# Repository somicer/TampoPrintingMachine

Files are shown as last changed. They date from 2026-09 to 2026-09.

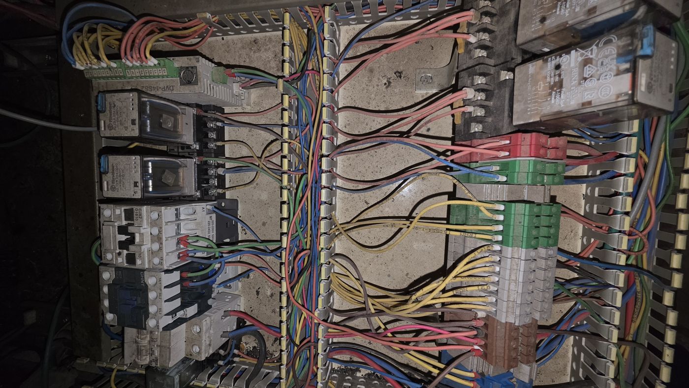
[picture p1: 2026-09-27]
docs/field_photos/panel_overview.jpg

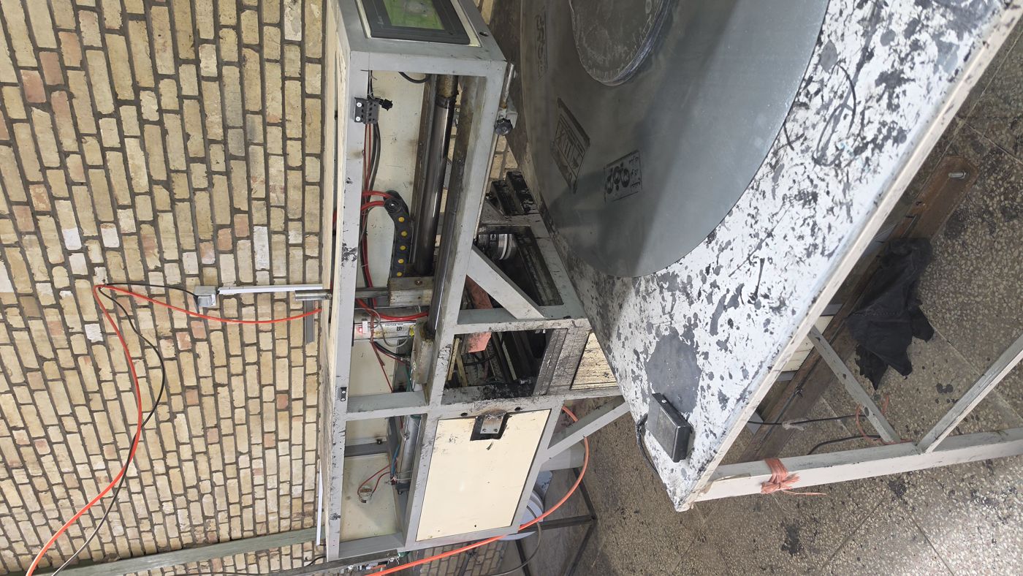
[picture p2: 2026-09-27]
docs/field_photos/machine_overview.jpg

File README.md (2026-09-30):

# سیستم کنترل دستگاه چاپ تامپو کاپ بسته‌ی بزرگ (Large-Format Closed-Cup Pad Printer)

کنترلر: **Delta DVP-28SV211T** · HMI: **Delta DOP-107BV** · درایور: **Leadshine CL57** + استپر کلوزلوپ NEMA24 · Z: پنوماتیک SMC MGPM

| فایل | محتوا |
|---|---|
| [docs/01_design_review.md](docs/01_design_review.md) | **نقد فنی طرح: مشکلات و پیشنهادها** (مطالعه‌ی آن پیش از ساخت ضروری است) |
| [docs/02_io_map.md](docs/02_io_map.md) | جدول کامل X، Y، M، D و T |
| [docs/03_state_machine.md](docs/03_state_machine.md) | ماشین وضعیت: هومینگ، اتومات، جوهرزنی و دستی |
| [docs/04_plc_program.md](docs/04_plc_program.md) | توضیح کد نردبانی، اینترلاک‌های ضدبرخورد و چک‌لیست راه‌اندازی |
| [docs/05_hmi.md](docs/05_hmi.md) | ساختار صفحات HMI، سطوح دسترسی و Recipe |
| [docs/06_electrical_safety_troubleshooting.md](docs/06_electrical_safety_troubleshooting.md) | تغذیه، ضد نویز، گراندینگ، مدار ایمنی، جدول آلارم‌ها و عیب‌یابی |
| [plc/TampoPrinter_SV2.il](plc/TampoPrinter_SV2.il) | برنامه‌ی کامل PLC (Instruction List) |
| [hmi/tag_list.csv](hmi/tag_list.csv) | فهرست Tagهای HMI |
| [hmi/hmi_mockup.html](hmi/hmi_mockup.html) | **نمونه‌ی تعاملی ۹ صفحه‌ی HMI** با آدرس هر شیء |
| [plc/TampoPrinter_SV2_clean.txt](plc/TampoPrinter_SV2_clean.txt) | برنامه‌ی PLC بدون توضیحات برای WPLSoft |
| [tools/plc_sim.py](tools/plc_sim.py) | شبیه‌ساز و تست خودکار برنامه‌ی PLC |
| [docs/07_bom_cost_estimate.md](docs/07_bom_cost_estimate.md) | برآورد هزینه‌ی قطعات (BOM) |
| [bom/bom_estimate.csv](bom/bom_estimate.csv) | فهرست قطعات و قیمت برای Excel |
| [docs/08_field_data_redesign.md](docs/08_field_data_redesign.md) | **داده‌های دستگاه موجود و طراحی از صفر** (معتبرترین بخش) |
| [docs/09_final_bom.md](docs/09_final_bom.md) | **لیست خرید نهایی طرح جدید** |
| [docs/10_operators_shifts_erp.md](docs/10_operators_shifts_erp.md) | **ورود کارگر، شیفت‌ها و ارسال آمار به ERP** |
| [tools/erp_gateway.py](tools/erp_gateway.py) | دروازه‌ی Modbus TCP به ERP |
| [docs/11_test_report.md](docs/11_test_report.md) | **گزارش تست نقطه‌به‌نقطه** (خودکار) |
| [docs/12_zones_error_handling.md](docs/12_zones_error_handling.md) | **مناطق ممنوع، مدیریت خطا و بازیابی نرم‌افزاری** |
| [tools/test_suite.py](tools/test_suite.py) | مجموعه‌ی تست (۴۶ سناریو، موازی) |
| [tools/axis_sizing.py](tools/axis_sizing.py) | محاسبه‌ی سرعت پیک، گشتاور، نسبت اینرسی و نیروی جک |
| [docs/13_3d_design.md](docs/13_3d_design.md) | **طراحی سه‌بعدی کل دستگاه** (قطعات و اسکلت)، راهنمای AutoCAD و ساخت |
| [cad/tampo_machine.py](cad/tampo_machine.py) | مدل پارامتریک CadQuery: خروجی STEP، DXF ورق‌ها، نقشه‌ی کلی، لیست برش و بررسی تداخل |
| [cad/out/tampo_viewer.html](cad/out/tampo_viewer.html) | نمایشگر سه‌بعدی با انیمیشن چرخه‌ی چاپ (در مرورگر باز کنید) |

## مهم‌ترین نتیجه‌ها (طرح نهایی بر اساس دستگاه موجود)

1. **Z پنوماتیک می‌ماند:** جک **SC63×100** (حدود ۱۶۰ کیلوگرم نیرو، مثل دستگاه فعلی)، به همراه شیر 3/8، شیر تخلیه‌ی سریع، رگولاتور جدا و پایلوت‌چک.
2. **X:** استپر کلوزلوپ ۴ N·m با گیربکس ۱:۳ و تسمه‌ی HTD5M عرض ۲۵. کورس ۷۵۰ mm با ریل HGR20 به طول ۱۰۶۰: پد تا ۴۴ سانت از بدنه بیرون می‌آید و روی **دیسک پلاستیکی** (مثلاً Ø1000/500) روی میز گردانِ پیچ‌شده به دستگاه چاپ می‌کند. جرم متحرک ۲۲ kg.
3. **Y:** همان استپر، مستقیم، روی **همان تسمه‌ی ۲۰ mm** دستگاه فعلی با پولی ۲۴ دندانه.
4. **سیکل:** جوهرزنی موازی، هم‌پوشانی حرکت X و Z، و برداشت زودتر. از **۱۰.۵ ثانیه** به حدود **۴.۵ تا ۵.۵ ثانیه**.
5. **ایمنی:** پرده‌ی نوری و رله‌ی ایمنی الزامی‌اند. اپراتور بعد از هر چاپ دستش را زیر پد می‌برد.
6. **اینترلاک ضدبرخورد:** سنسور ارتفاع امن (X20) و آلارم‌های A10 و A17 که قانون «پد روی سطح = X ساکن» را تضمین می‌کنند.

> ⚠️ کد یک **طرح مرجع** است و روی سخت‌افزار واقعی تست نشده است. شماره‌ی رجیسترها و بیت‌های ویژه‌ی SV2 را با دفترچه‌ی فریمور خودتان تطبیق دهید. PLC استاندارد جایگزین مدار ایمنی نیست.

## اجرای محاسبات

```bash
python3 cad/tampo_machine.py      # مدل سه‌بعدی و همه‌ی خروجی‌های ساخت (نیاز: pip install cadquery ezdxf)
python3 tools/axis_sizing.py
```

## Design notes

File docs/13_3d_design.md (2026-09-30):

# ۱۳. طراحی سه‌بعدی دستگاه (قطعات و اسکلت)

> **نمایشگر سه‌بعدی:** فایل [`cad/out/tampo_viewer.html`](../cad/out/tampo_viewer.html) را در مرورگر باز کنید. چرخه‌ی چاپ را پخش کنید، قطعه‌ها را بچرخانید، باز کنید، برش بزنید و روی هر قطعه کلیک کنید.
> **مدل اصلی:** [`cad/tampo_machine.py`](../cad/tampo_machine.py) (پارامتریک، CadQuery). هر عددی را در بالای این فایل عوض کنید و دوباره اجرا کنید تا همه‌ی فایل‌ها دوباره ساخته شوند.

## ۱۳-۱ چه فایل‌هایی ساخته شد و هر کدام به چه درد می‌خورد

| فایل | برای چه |
|---|---|
| `cad/out/tampo_assembly.step` | **کل دستگاه** با ۲۱۲ قطعه‌ی جامد و رنگی (همراه میز دیسک و پیچ‌ها). در AutoCAD، SolidWorks، Inventor، Fusion یا FreeCAD (رایگان) باز می‌شود |
| `cad/out/parts_step/*.step` | **هر قطعه‌ی ساختنی جدا** (لوله‌ها `T..`، ورق‌ها `P..`، قطعات تراش/فرز `M..`) در مختصات خودش، برای نقشه‌کشی قطعه‌به‌قطعه |
| `cad/out/dxf/*.dxf` | **نقشه‌ی تخت ورق‌ها** در مقیاس ۱:۱ میلی‌متر، با همه‌ی سوراخ‌ها و شیارها. مستقیم به کارگاه برش لیزر یا واترجت بدهید |
| `cad/out/tampo_GA.dxf` | **نقشه‌ی کلی** در سه نما (کنار، روبه‌رو و بالا) با خطوط پنهان و اندازه‌های اصلی |
| `cad/out/cut_list.csv` | **لیست برش لوله‌ها:** پروفیل، طول، تعداد و تعداد شاخه‌ی ۶ متری |
| `cad/out/parts_list.csv` | **لیست کامل قطعات:** کد، نام، جنس، اندازه، تعداد، جرم و روش ساخت (با Excel باز می‌شود) |
| `cad/out/check_report.md` | **گزارش بررسی خودکار:** تداخل، فاصله‌ها، سفتی سازه، جرم‌ها و کنترل دوباره‌ی موتور |

**کدگذاری قطعات:**
* `T` = لوله‌ی اسکلت (برش اره و جوش).
* `P` = ورق (برش لیزر، سپس سوراخ‌کاری یا قلاویز).
* `M` = قطعه‌ی تراش یا فرز.
* `B` = قطعه‌ی خریدنی. شکل آن‌ها نزدیک به واقعی است (بخش ۱۳-۱۱)، ولی ابعاد نصب را با کاتالوگ تطبیق دهید.
* `F` = پیچ و مهره. تعداد هر ردیف در `parts_list.csv` آمده است.

## ۱۳-۲ کار با AutoCAD

1. **باز کردن مدل سه‌بعدی:** فرمان `IMPORT` و انتخاب `tampo_assembly.step`. هر قطعه یک Solid سه‌بعدی می‌شود.
2. **نقشه‌ی دوبعدی با اندازه:** در AutoCAD کامل (نه LT)، فرمان `VIEWBASE` روی مدل وارد‌شده یا روی هر فایل `parts_step/*.step`. نماهای روبه‌رو، بالا، کنار و ایزومتریک خودکار ساخته می‌شوند. بعد با `DIM` اندازه بگذارید. اگر مدل را عوض کنید، نماها به‌روز می‌شوند.
3. **ورق‌ها:** فایل‌های `dxf/*.dxf` را مستقیم باز کنید. لایه‌ی `CUT` لبه‌ی بیرونی و بریدگی‌هاست، `HOLES` سوراخ‌ها و شیارها، `DIM` اندازه‌ها و `TEXT` مشخصات.
4. **AutoCAD LT** مدل سه‌بعدی را باز نمی‌کند. با LT از `tampo_GA.dxf` و فایل‌های `dxf/` استفاده کنید.

> **سوراخ‌های قلاویزی:** در DXF قطر **مته‌ی قلاویز** کشیده شده، مثلاً Ø4.2 برای M5، Ø6.8 برای M8 و Ø10.2 برای M12. این سوراخ‌ها را با لیزر نبرید. جای آن‌ها را علامت بزنید و در کارگاه مته و قلاویز کنید. توضیح هر ورق در ستون `note` فایل `parts_list.csv` آمده است.

## ۱۳-۳ چیدمان دستگاه

**قطعه‌کار:** دیسک پلاستیکی به ضخامت ۲ mm، مثلاً قطر بیرونی ۱۰۰۰ و قطر داخلی ۵۰۰ mm. دیسک روی **میزی بیرون از بدنه‌ی دستگاه** قرار می‌گیرد. پد از بدنه **بیرون می‌آید** و روی حلقه‌ی دیسک چاپ می‌کند. اپراتور بعد از هر چاپ دیسک را می‌چرخاند.

```
  نمای کنار (از سمت چپ)
                    ◄─ بدنه 600 ─►◄──────── پد تا 440 mm بیرون می‌آید ────────►
                    ┌──────────────╥════════ دو تیر X (یک‌سرآزاد) ═════════════╗
       موتور X ▣════╪══ تسمه ═════╬═[کالسکه+جک Z]══════════════════════ هرزگرد ╣
                    │ پرتال عقب    ║ ستون جلو    │ پد                          │
                    │  کلیشه + کاپ ║ (پنجره‌ی پد) ▼                            │
                    │ ═════════════╣      ┌──────────────── دیسک Ø1000 ────────────┐
                    │  قاب SHS60   ║══════╡ میز گردان روی بلبرینگ (Lazy Susan)     │
                    │              ║ لوله‌ی اتصال │  قاب میز SHS60                │
                    └──────────────╨══════════════┴───────────────────────────────┘
                                   ↑ میز دیسک با ۴ لوله به بدنه پیچ می‌شود
```

| اندازه | مقدار (mm) |
|---|---:|
| ابعاد کلی (بدنه، تیرها، میز دیسک، تابلو، HMI) | حدود 1870 × 1300 × 1650 |
| بدنه‌ی دستگاه | 600 × 950، ارتفاع قاب 880 |
| **ارتفاع کار** (روی کلیشه = روی دیسک) | **945** |
| کورس کامل X | **750** (پد تا **440** جلوتر از بدنه) |
| محل برداشت / چاپ پیش‌فرض (دیسک Ø1000/500، وسط حلقه، شعاع 375) | X = 50 / X = 495 |
| دیسک Ø800/400 و Ø600/300 (با همان مرکز میز) | X = 570 و X = 645 |
| جای دست بالای دیسک تا زیر تیرها | 272 |
| جرم بدنه (بدون تابلو) / میز دیسک | حدود ۳۲۵ / ۱۳۰ کیلوگرم |

**محورها:**
* **X** جهت حرکت پد به سمت میز دیسک است.
* **محور کاپ** (Y در برنامه‌ی PLC) مثل دستگاه فعلی **۹۰ درجه با X** است. کلیشه در جهت Y قرار دارد و کاپ ۳۷۰ mm به سمت چپ می‌رود.
* **Z** رو به بالاست.

**محل چاپ برای هر دیسک:** مرکز دیسک همیشه روی **مرکز میز گردان** است. برای هر قطر، فقط عدد «محل چاپ» (D502) روی صفحه‌ی اصلی HMI عوض می‌شود:

**محل چاپ = 1160 − 290 − شعاع چاپ**

مثلاً برای دیسک Ø1000/500 و چاپ وسط حلقه (شعاع 375): 1160 − 290 − 375 = **495**. در دستورهای کار (Recipe) نمونه‌ی سه قطر آماده گذاشته شده است.

## ۱۳-۴ تصمیم‌های طراحی و دلیلشان

| بخش | طراحی | چرا |
|---|---|---|
| **بدنه** | بدنه‌ی کوتاه (۶۰۰ mm) که فقط ایستگاه جوهر، موتورها و برق را دارد. قاب جوشی **SHS 60×60×4** | هرچه کلیشه به جلوی بدنه نزدیک‌تر باشد، مسیر پد تا دیسک کوتاه‌تر است |
| **تیرهای X** | دو تیر **RHS 120×60×5** روی **پرتال عقب** و **دو ستون جلو که درست زیر تیرها هستند**. تیرها **۶۶۰ mm از ستون جلو بیرون می‌زنند** و سرشان با یک عرضی به هم بسته است | پد از **پنجره‌ی** بین دو ستون جلو بیرون می‌رود. تیر بزرگ‌تر از قبل انتخاب شد چون حالا **یک‌سرآزاد** است. در بیشترین دسترسی و با فشار کامل جک، خیز فقط **۰.۰۹ mm** است |
| **نیرو در ستون جلو** | پیچ تیر به ستون جلو **کشش** دارد (حدود ۲ kN در بیشترین دسترسی) | فشار چاپ پد را به بالا هل می‌دهد و سر تیرها را بلند می‌کند. ۴ پیچ M10 در هر اتصال چند برابر این نیرو را تحمل می‌کنند |
| **میز دیسک** | قاب **SHS 60×60×4** با **۴ لوله‌ی اتصال پیچی به بدنه** (بالا و پایین). صفحه‌ی گردان Ø1050 روی **بلبرینگ گردان Ø500**. **حلقه‌ی مرکزگیر** قابل تعویض برای هر قطر داخلی. **پین شاخص** برای سه چاپ با زاویه‌ی ۱۲۰ درجه | اگر میز جدا باشد، فشار چاپ **جلوی دستگاه را از زمین بلند می‌کند** (محاسبه در گزارش: ۲۰۱۹ N·m گشتاور بلندکننده در برابر ۱۳۳۱ N·m وزن). با اتصال پیچی، نیرو داخل فولاد بسته می‌شود. صفحه‌ی گردان چرخاندن دیسک ۱ متری را راحت و دقیق می‌کند |
| **ریل X** | دو **HGR20 طول ۱۰۶۰** (کورس ۷۵۰ + جای اضافه‌ی ۴۰ mm در هر سر) روی **تسمه‌ی فولادی سنگ‌خورده 40×15** | تسمه‌ی سنگ‌خورده با شیم تراز می‌شود و به فرز کردن کل اسکلت نیازی نیست |
| **کالسکه و هد Z** | همان طرح قبل: صفحه‌ی آلومینیوم ۱۵ mm، جک **SC63×100**، دو میله‌ی **Ø25** در **LMF25**، مفصل شناور، و اسلاید دستی ارتفاع پد با پیچ فشاری M12 | جرم متحرک ۲۱.۹ kg |
| **سنسورهای Z** | به‌جای سنسور مگنتی روی جک: **سه سنسور القایی M12** (PR12-4DN) روی براکت شیاری `P17` زیر کالسکه، رو به یک **تسمه‌ی آهنی 3×20×40** (`P16`) که به صفحه‌ی سر پیچ شده. طول تسمه‌ی آهنی = ناحیه‌ی امن | سنسور ارتفاع امن (X20) حالا **ناحیه‌ای** است: از بالا تا ارتفاع امن پیوسته روشن است. PLC فقط `M26 = X20` می‌خواند؛ قطع سیم یا افتادن تسمه‌ی آهنی یعنی «ناامن» و X حرکت نمی‌کند. نقطه‌های قطع در بخش ۸ گزارش بررسی است |
| **محرک X** | تسمه‌ی HTD5M عرض ۲۵ **بین دو ریل** (۱۰۰ mm کنار مرکز). موتور و گیربکس **پشت کالسکه**. هرزگرد با شیار کشش روی **عرضی سر تیرها** | بخش ۱۳-۱۰ |
| **ایستگاه جوهر** | کلیشه در جهت Y، کاپ Ø140 روی بازو با ۳ پین فنری، ریل **HGR15** پشت کلیشه، و تسمه‌ی ۲۰ با موتور مستقیم | کاپ آزادانه روی کلیشه صاف می‌نشیند |
| **برق** | تابلو ۶۰×۸۰ روی بدنه‌ی راست. **HMI در گوشه‌ی جلو-راست، رو به میز دیسک**. یک E-Stop روی HMI و یکی روی پایه‌ی میز. پدال کنار میز | اپراتور کنار میز دیسک می‌ایستد |
| **محافظ‌ها** | بدنه با پلی‌کربنات بسته است، به‌جز **پنجره‌ی پد** در جلو. درب لولایی با سوئیچ ایمنی روی ایستگاه جوهر | دست فقط به دیسک و زیر مسیر پد می‌رسد |

## ۱۳-۵ بررسی‌های خودکار (نتیجه‌ی اجرای مدل)

جزئیات کامل در [`cad/out/check_report.md`](../cad/out/check_report.md) است.

* **تداخل:** قطعه‌های ثابت هیچ تداخلی ندارند. در **۷ حالت حرکتی** هیچ برخوردی نیست: خانه، برداشت با پد پایین، انتظار برداشت زودتر، **عبور پد از پنجره‌ی جلو**، چاپ روی دیسک، و بیشترین دسترسی با پد بالا و پایین.
* **فاصله‌ها:**
  * هد Z هنگام عبور از پنجره، ۵۰ mm با ستون‌های جلو فاصله دارد.
  * پد (بالا) ۲۰ mm بالای لبه‌ی پایین پنجره است.
  * پد (بالا) ۳۳ mm بالای بازوی کاپ است.
* **سفتی:** خیز سر تیرها زیر نیروی کامل جک (۱۵۹۰ N): ۰.۰۱ mm در چاپ دیسک Ø1000 و **۰.۰۹ mm** در بیشترین دسترسی.
* **موتور X:** جرم متحرک ۲۱.۹ kg است. گشتاور لازم ۰.۵۷ N·m در برابر ۱.۲ تا ۱.۵ N·m موجود، یعنی **۲.۱ تا ۲.۶ برابر حاشیه**. کورس بلندتر فقط زمان حرکت را بیشتر می‌کند و زور بیشتری نمی‌خواهد.
* **برنامه‌ی PLC:** مقدارهای پیش‌فرض عوض شد: برداشت ۵۰، چاپ ۴۹۵ و حد نرم‌افزاری X ۷۵۰ mm. هر ۵۷ سناریوی تست دوباره قبول شدند.

## ۱۳-۶ راهنمای ساخت

1. **لوله‌ها** را طبق `cut_list.csv` ببرید. همه‌ی برش‌ها ۹۰ درجه‌اند.

   | پروفیل | کل طول | تعداد شاخه‌ی ۶ متری |
   |---|---:|---:|
   | SHS 60×60×4 (بدنه و میز دیسک) | ۲۳.۸ متر | ۵ |
   | RHS 120×60×5 (تیرهای X) | ۳.۰ متر | ۱ |
   | SHS 40×40×3 | ۰.۹ متر | ۱ |

2. **ترتیب جوش:**
   1. قاب بدنه و قاب میز دیسک را **جدا** روی میز صاف جوش دهید.
   2. خال‌جوش بزنید، قطرها را بسنجید (اختلاف کمتر از ۲ mm)، و بعد جوش کامل ضربدری بدهید.
   3. ستون‌های جلو و پرتال عقب را جوش دهید.
3. **میز دیسک را به بدنه پیچ کنید**: ۴ لوله‌ی اتصال، هر سر با ورق فلنج `P61` (120×60×10) و ۲ پیچ M12 با مهره و واشر. پیش از سفت کردن، سطح میز گردان را با تراز روی **۹۴۳** بیاورید.
4. **تیرهای X** را پیچ کنید، جوش نکنید: ۴ پیچ M10 روی پرتال عقب و ۴ پیچ روی هر ستون جلو. بعد عرضی سر تیرها را ببندید.
5. **تراز کردن ریل‌ها:** ریل اول را با ساعت اندیکاتور صاف کنید (خطای کمتر از ۰.۰۲ mm). ریل دوم را نسبت به اولی موازی کنید و زیر تسمه‌ها شیم بگذارید.
6. **ورق‌ها** را از روی `dxf/` لیزر کنید. سوراخ‌های مته‌ی قلاویز را فقط علامت بزنید.
7. **تراشکاری:** میله‌های Ø25 (h6، سخت‌کروم)، پایه‌ی کلیشه (فرز و سنگ)، صفحه‌ی گردان (CNC)، و حلقه‌ی مرکزگیر POM برای هر قطر داخلی دیسک.
8. **رنگ:** اسکلت ضدزنگ و کوره‌ای (مدل RAL 7016). سطح ریل‌ها و پایه‌ی کلیشه را رنگ نکنید.

## ۱۳-۷ فرض‌ها: پیش از ساخت تأیید کنید

| مورد | فرض مدل | کجا اثر دارد |
|---|---|---|
| **کورس X** | **۷۵۰ mm** (پد تا ۴۴۰ mm جلوتر از بدنه). ریل **۱۰۶۰ mm**، یعنی حدود ۴۰ mm جای اضافه بعد از واگن‌ها در هر سر | اگر کورس عوض شد، عدد `x_travel` را در مدل عوض کنید. طول ریل (استاندارد HIWIN)، تیرها، تسمه و حد نرم‌افزاری خودکار حساب می‌شوند |
| میز دیسک | **جدید**، بخشی از دستگاه و پیچ‌شده به بدنه | اگر می‌خواهید از میز گرد فعلی استفاده کنید، آن را با لوله به بدنه ببندید یا دستگاه را با رول‌بولت به زمین محکم کنید (بخش ۴ گزارش) |
| فاصله‌ی لبه‌ی دیسک تا بدنه | ۶۰ mm | مرکز میز در X = 1160 |
| فلنج جلوی جک SC63 (FA) | ۴ سوراخ Ø9 در 50×100، سوراخ وسط Ø40 | صفحه‌ی کالسکه `P10` |
| گیربکس PLF60 1:3 | فلنج خروجی ۴×M5 روی PCD 70 | براکت موتور `P21` |
| استپر NEMA24 | ۴ سوراخ روی مربع 47.14 | براکت موتور کاپ `P33` |
| کاپ فعلی | قطر ۱۴۰، ارتفاع ۴۵ | بازوی کاپ `P31` |
| کلیشه | فولادی ضخیم ۱۰ mm | ضخامت پایه‌ی کلیشه `P30` |
| تسمه‌ی کاپ | همان تسمه‌ی گام ۵ عرض ۲۰ فعلی | پولی `B12` |

**برای عوض کردن هر فرض:** مقدار را در بخش `PARAMETERS` بالای `cad/tampo_machine.py` عوض کنید، مثلاً `reach`، `disc_od`، `disc_id` یا `disc_gap`. بعد `python3 cad/tampo_machine.py` را اجرا کنید (حدود ۱۰ ثانیه) تا همه‌ی فایل‌ها و بررسی‌ها دوباره ساخته شوند.

## ۱۳-۸ ⚠️ ایمنی: حالا خطر روی میز دیسک است

اپراتور بعد از **هر** چاپ دستش را روی دیسک، زیر مسیر پد می‌برد. میز باز است و حدود یک متر قطر دارد، پس **پرده‌ی نوری جلوی بدنه دیگر جای مفیدی ندارد** و در مدل حذف شد. پیشنهاد به ترتیب اهمیت:

1. **فرود دومرحله‌ای با نیروی کم (اصلی):** پد با فشار کم پایین می‌آید (نیروی کمتر از ۱۵۰ N که دست را له نمی‌کند). فقط وقتی سنسور «پایین» روشن شد، فشار کامل وصل می‌شود. این کار یک رگولاتور، یک شیر کوچک و تغییر کوچکی در برنامه‌ی PLC لازم دارد.
2. **شروع فقط وقتی دست بیرون است:** یک **اسکنر ایمنی لیزری** (Area Scanner) که ناحیه‌ی زیر مسیر پد روی میز را می‌پاید، **به‌جای پرده‌ی نوری**. گران‌تر از پرده‌ی نوری است، ولی برای میز باز مناسب‌تر است. در لیست خرید (بخش ۹) هنوز پرده‌ی نوری آمده است. اگر اسکنر را انتخاب کنید، آن ردیف عوض می‌شود.
3. **فشار چاپ را پایین بیاورید:** برای دیسک پلاستیکی ۲ میلی‌متری معمولاً فشار کامل ۵ بار لازم نیست. با رگولاتور Z، فشار را به کمترین مقداری برسانید که چاپ خوب می‌دهد. نیروی کمتر هم برای ایمنی و هم برای تیرها بهتر است.

> این تصمیم با شماست. تا یکی از راه‌های ۱ یا ۲ اجرا نشده، دستگاه **برای کار با دست زیر پد ایمن نیست**. سوئیچ ایمنی درب ایستگاه جوهر (`B61`) باید در مدار **رله‌ی ایمنی** سری شود.

## ۱۳-۹ قطعات مکانیکی خریدنی که در لیست خرید بخش ۹ نیستند

تعداد دقیق همه در `parts_list.csv` است.

* **کاپ:** ریل **HGR15 طول ۴۶۰** و یک واگن **HGH15CA**.
* **سنسورهای Z:** براکت `P17` و تسمه‌ی آهنی `P16` ساختنی‌اند. خود سه سنسور در لیست خرید بخش ۹ آمده است.
* **هد Z:** دو **LMF25UU**، دو میله‌ی **Ø25×210 سخت‌کروم**، **مفصل شناور M16×1.5**، **فلنج FA** جک، پیچ M12.
* **میز دیسک:** **بلبرینگ گردان (Lazy Susan) Ø500** با ظرفیت ۲۰۰ kg یا بیشتر، **صفحه‌ی گردان Ø1050** (MDF روکش‌دار یا کامپوزیت آلومینیوم)، **حلقه‌های مرکزگیر POM** برای هر قطر داخلی، و **پین شاخص فنری**.
* **اسکلت:** ده **پایه‌ی ترازشو M16** (۶ برای بدنه، ۴ برای میز)، و زیر هر پایه ورق کف `P62` با مهره‌ی M16 جوش‌شده.
* **محافظ‌ها:** ورق **پلی‌کربنات ۵ mm** (حدود ۱.۵ متر مربع)، لولا، **سوئیچ ایمنی درب**.
* **زنجیر کابل** 25×50 به طول حدود ۱.۷ m با سینی.
* **فولاد و آلومینیوم:** لوله‌ها طبق لیست برش، ورق فولادی ۱۰ تا ۱۵ mm، ورق آلومینیوم ۱۲ تا ۲۰ mm، تسمه‌ی فولادی 40×15، و بلوک ۴۵ mm برای پایه‌ی کلیشه.

## ۱۳-۱۰ آیا تسمه باید حتماً به وسط کالسکه وصل شود؟

**نه، با ریل‌های واگن‌دار (HGR) لازم نیست.** ولی هرچه نزدیک‌تر به مرکز باشد بهتر است.

* **چه اتفاقی می‌افتد؟** وقتی تسمه کنار مرکز کالسکه می‌کشد، علاوه بر هل دادن، کالسکه را کمی **می‌پیچاند**، مثل وقتی یک کشو را از گوشه‌اش می‌کشید. مقدار پیچش = نیرو × فاصله از مرکز.
* **چه کسی جلوی پیچش را می‌گیرد؟** ۴ واگن روی دو ریل. هر واگن HGR20 حدود **۱۷٬۷۵۰ نیوتن** ظرفیت دارد. در این طرح، پیچش فقط حدود **۳۰ نیوتن** روی هر واگن می‌اندازد، یعنی **کمتر از ۰.۲٪** ظرفیتش. پس هیچ مشکلی ایجاد نمی‌کند (جزئیات در بخش ۷ گزارش بررسی).
* **کجا مشکل‌ساز است؟** در **شفت گرد با بوش ساده** (مثل دستگاه فعلی شما). آنجا بوش لقی دارد و کشیدن از کنار باعث **کج شدن و گیر کردن** می‌شود، مثل کشوی قدیمی. قاعده‌ی تجربی این است که فاصله‌ی دو بوش در جهت حرکت حداقل ۲ برابر فاصله‌ی نیرو تا مرکز باشد. اگر محور X را با همان شفت‌های Ø45 فعلی بسازید، تسمه را حتماً **در وسط** بگذارید.
* **در این طرح چه کردیم:** تسمه را از بیرون ریل (۲۱۵ mm از مرکز) به **داخل، بین دو ریل (۱۰۰ mm از مرکز)** آوردیم تا پیچش نصف شود. وسطِ وسط ممکن نیست، چون جک Z و میله‌های راهنمای پد آنجا هستند.

## ۱۳-۱۱ جزئیات مدل و لیست پیچ و مهره

مدل حالا قطعه‌ها را با شکل نزدیک به واقعی نشان می‌دهد، تا هم نقشه‌ها گویاتر باشند و هم تداخل‌ها واقعی‌تر سنجیده شوند:

| قطعه | جزئیات در مدل |
|---|---|
| ریل HGR20 و HGR15 | مقطع با شیار کناری، سوراخ‌های خزینه‌دار با گام ۶۰، و پیچ‌های آلن داخل خزینه |
| واگن HGH20CA و HGH15CA | بدنه‌ی فولادی با ۴ سوراخ M5/M4، آب‌بند دو سر (قرمز)، و گریس‌خور |
| استپر NEMA24 | بدنه‌ی گوشه‌پخ، فلنج با ۴ سوراخ روی مربع 47.14، انکودر پشت با کانکتور، و محور |
| گیربکس PLF60 | فلنج مربعی خروجی با ۴ سوراخ روی PCD 70 و بدنه‌ی گرد |
| جک SC63×100 | دو درپوش مربعی ۷۵، لوله‌ی Ø70، ۴ تای‌راد با مهره، پیچ‌های کوشن، و درگاه‌ها |
| پولی‌ها | ۲۴ دندانه‌ی HTD 5M، دو فلنج، و توپی |
| تسمه‌ها | حلقه‌ی کامل دور دو پولی (رشته‌ی بالا داخل گیره‌ی کالسکه) |
| زنجیر کابل | حلقه‌های جدا با گام ۲۵ و خم U |
| شیر 4V320 | بدنه، دو کویل با کانکتور، و سه اتصال |
| بوش LMF25 / LMF20 | فلنج با ۴ سوراخ و بدنه |
| پایه‌ها | ورق کف جوشی `P62`، پایه‌ی ترازشو با کف لاستیکی، و مهره‌ی قفل |
| پرتال‌ها | ۴ **لچکی** ۱۰۰×۱۰۰×۸ (`P63`) در گوشه‌ی داخلی ستون و تیر عرضی، برای سفتی جانبی |
| میز دیسک | فلنج‌های پیچی `P61`، و **۳ سوراخ شاخص ۱۲۰ درجه** در صفحه‌ی گردان برای پین شاخص |
| تابلو، HMI، چراغ برج، E-Stop، FRL | درب با دریچه‌ی هوا، دستگیره و لولا، گلند کابل؛ صفحه‌ی لمسی و ۳ شستی؛ سه طبقه‌ی رنگی؛ قارچی قرمز |
| ورق‌های آلومینیومی | گوشه‌ی گرد (R6 تا R10) در مدل و در DXF |

**لیست پیچ و مهره (از `parts_list.csv`، کدهای `F`):**

| کد | پیچ | تعداد | کجا |
|---|---|---:|---|
| F01 | آلن M5×20 | 42 | ریل‌های X |
| F02 | آلن M5×25 | 16 | واگن‌های X به کالسکه |
| F03 | آلن M8×25 | 4 | فلنج جک |
| F04 | آلن M6×30 + مهره | 8 | بوش‌های LMF25 |
| F05 | آلن M6×20 | 6 | صفحه‌های کناری هد Z |
| F06 | آلن M12×25 | 2 | میله‌های راهنما به صفحه‌ی سر |
| F07 | آلن M10×30 + واشر | 4 | شیار تنظیم ارتفاع پد |
| F08 | آلن M8×20 + واشر | 8 | پایه‌ی براکت‌های موتور و هرزگرد |
| F09 | آلن M4×16 | 8 | ریل کاپ |
| F10 | آلن M4×12 | 4 | واگن کاپ |
| F11 | آلن M12×40 + مهره و واشر | 16 | اتصال میز دیسک |

پیچ‌های اتصال تیرهای X به پرتال و ستون جلو (M10، قلاویز در ورق جوشی)، پیچ‌های خزینه‌ی M8 تسمه‌ی ریل، و پیچ‌های کلیشه و محافظ‌ها **در مدل کشیده نشده‌اند**. هنگام خرید حدود ۲۰٪ به همه‌ی ردیف‌ها اضافه کنید.

> **یک اصلاح طراحی که همین بررسی پیدا کرد:** سوراخ‌های پیچ پایه‌ی براکت موتور X و هرزگرد، و پایه‌ی براکت‌های کاپ، **زیر دیواره‌ی عمودی براکت** افتاده بودند، جایی که پیچ اصلاً جا نمی‌شود. سوراخ‌ها به بیرون از دیواره منتقل شدند و DXF آن‌ها (`P20`، `P22`، `P33F`، `P34F`) به‌روز شد.

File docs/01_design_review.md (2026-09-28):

# ۱. نقد فنی طرح پیشنهادی: مشکلات و پیشنهادها

> ⚠️ **این بخش بر اساس اطلاعات اولیه (Gemini) نوشته شده است.** برای طرح جدید و قطعات نهایی، [بخش ۸](08_field_data_redesign.md) و [بخش ۹](09_final_bom.md) را ببینید. نکته‌های ایمنی، نویز و منطق کلی همچنان معتبرند.

> این بخش پیش از کد آمده است، چون چند مورد از مشکلات زیر روی **آدرس‌دهی I/O، لاجیک ایمنی و خود سیکل** اثر مستقیم دارند.
> اعداد با اسکریپت `tools/axis_sizing.py` محاسبه شده‌اند و با تغییر ورودی‌ها قابل بازتولیدند.

## خلاصه‌ی اولویت‌ها

| # | موضوع | شدت | خلاصه |
|---|---|---|---|
| 1 | نیروی جک Z (MGPM25) | 🔴 بحرانی | در 6 بار فقط حدود 295 نیوتن فشار می‌دهد. برای پد بزرگ و کاپ ۱۳۰ کم است |
| 2 | شیر دوبوبین + جک عمودی در E-Stop و قطع هوا | 🔴 ایمنی | پد ممکن است پایین بماند یا با وزن خودش سقوط کند |
| 3 | سنسور Z_Down روی جک (پد قبل از انتهای کورس می‌نشیند) | 🔴 عملکردی | ارتفاع کلیشه و قطعه فرق دارد، پس سنسور در یکی از دو ایستگاه عمل نمی‌کند |
| 4 | پدال تنها برای ماشینی که نیروی له‌کنندگی دارد | 🔴 ایمنی | پرده‌ی نوری یا گارد لازم است (ISO 12100 / 13849) |
| 5 | نسبت اینرسی محور X در حدود ۴۱:۱ | 🟠 مهم | خطر رزونانس، اورشوت و خطای Position در CL57 |
| 6 | سرعت پیک واقعی X حدود ۷۰۰ mm/s است، نه ۴۵۰ | 🟠 مهم | عدد ۳۵۰ تا ۴۵۰ سرعت میانگین است |
| 7 | ولتاژ ۴۸V نزدیک سقف CL57 | 🟠 مهم | برق برگشتی (Regen) در ترمز محور ۱۰ کیلویی |
| 8 | سنسور هوم NO و نبود لیمیت سخت‌افزاری | 🟠 مهم | اگر سیم قطع شود، هومینگ تا برخورد به انتهای کورس ادامه پیدا می‌کند |
| 9 | ترتیب سیکل (بازگشت به X0 و حرکت‌های سریالی) | 🟡 بهره‌وری | حدود ۴۰٪ ظرفیت تولید از دست می‌رود |
| 10 | کوپل صلب کاپ به تسمه‌ی Y | 🟡 کیفیت | نشتی رنگ و سایش رینگ سرامیکی |
| 11 | دکمه‌های Jog روی HMI از طریق Modbus | 🟡 ایمنی | اگر کابل قطع شود، بیت ممکن است ON بماند و محور همچنان حرکت کند |

---

## ۱-۱ 🔴 نیروی چاپ جک Z کافی نیست

| جک (در 6 بار) | نیروی فشار (رو به پایین) | نیروی کشش (رو به بالا) |
|---|---|---|
| **MGPM25 (طرح فعلی)** | **295 N** | 247 N |
| MGPM32 | 483 N | 390 N |
| MGPM40 | 754 N | 662 N |
| **MGPM50 (پیشنهادی)** | **1178 N** | 1025 N |
| MGPM63 | 1870 N | 1718 N |

* کاپ ۱۳۰ میلی‌متری یعنی تصویر تا حدود Ø110 mm. پد سیلیکونی مناسب این تصویر (معمولاً ۱۲۰ تا ۱۶۰ میلی‌متر) برای انتقال کامل رنگ معمولاً **۸۰۰ تا ۲۰۰۰ نیوتن** نیرو لازم دارد. هرچه پد بزرگ‌تر و سخت‌تر باشد، نیروی بیشتری لازم است.
* **تمام** ۲۹۵ نیوتن جک ۲۵ صرف فشردن پد نمی‌شود. بخشی از آن صرف اصطکاک بوش‌ها و مقاومت فلوکنترل Meter-Out می‌شود.
* **پیشنهاد:** جک **MGPM50-xx** (با جک ۶۳ برای پدهای خیلی سخت). پایه و براکت Z را هم برای این نیرو طراحی کنید. واکنش این نیرو به کالسکه‌ی X و ریل‌ها برمی‌گردد، نه به تسمه. اگر ریل‌های X سبک باشند، در لحظه‌ی چاپ خم می‌شوند و تصویر دوبل (Ghost) می‌افتد.
* **پیشنهاد:** یک **رگولاتور دقیق** مخصوص خط Z بگذارید (مثل SMC IR2000) یا در نسخه‌ی پیشرفته رگولاتور **تناسبی ITV** (0–10V از ماژول آنالوگ). در این صورت «فشار چاپ» یک پارامتر دستور کار (Recipe) می‌شود.

## ۱-۲ 🔴 شیر ۵/۲ دوبوبین روی جک عمودی

دو سناریوی خطرناک:

1. **E-Stop در حالی که پد پایین است:** شیر دوبوبین آخرین وضعیت را نگه می‌دارد. اگر رله‌ی ایمنی برق هر دو بوبین را قطع کند، پد **پایین می‌ماند** و ممکن است دست اپراتور زیر آن گیر بیفتد.
2. **قطع هوا یا تخلیه‌ی هوای اصلی (Dump) در E-Stop:** جک عمودی با وزن پد و براکت **سقوط آزاد** می‌کند.

**پیشنهاد (به ترتیب ترجیح):**

| راهکار | توضیح |
|---|---|
| **A (کمترین تغییر، در همین کد پیاده شده)** | بوبین **Down (Y4)** از کنتاکت NO رله‌ی ایمنی تغذیه شود. بوبین **Up (Y5)** از 24V معمولی. در E-Stop، PLC بوبین Up را روشن نگه می‌دارد و پد **بالا می‌رود** که جهت ایمن است. **هوای اصلی در E-Stop تخلیه نمی‌شود.** |
| **B (بهترین)** | به‌جای دوبوبین، شیر **تک‌بوبین فنری (Monostable)** که بوبین آن معادل Down است. با قطع برق، پد خودبه‌خود بالا می‌رود. |
| **C (مکمل الزامی)** | یک **شیر یک‌طرفه‌ی پایلوت‌دار** (Pilot Check Valve، مثل SMC XT34 یا AS-R) روی پورت Rod-Side (همان پورتی که پد را بالا نگه می‌دارد). در قطع هوا، پد در بالا قفل می‌ماند. |
| **D** | شیر Soft-Start/Dump (مثل SMC AV) فقط برای **قفل و برچسب تعمیرات (LOTO)** استفاده شود، نه برای E-Stop عادی. |

## ۱-۳ 🔴 سنسور Z_Down و اختلاف ارتفاع کلیشه و قطعه

* پد سیلیکونی **پیش از انتهای کورس** روی سطح می‌نشیند و فشرده می‌شود. جک به انتهای ۲۰۰ میلی‌متری نمی‌رسد. سنسور شیاری D-M9N روی بدنه‌ی جک فقط نشان می‌دهد «پیستون به این نقطه رسیده است».
* ارتفاع سطح کلیشه و سطح قطعه تقریباً هیچ‌وقت یکی نیست. اگر سنسور را برای کلیشه تنظیم کنید، روی قطعه یا دیر عمل می‌کند یا اصلاً عمل نمی‌کند. نتیجه‌اش **Timeout** یا فشار نامساوی است.
* **شاک‌آبزوربر هیدرولیکی در انتهای پایین** با فلسفه‌ی «کنترل با نیرو» تداخل دارد. اگر پد به شاک‌آبزوربر برسد، بخشی از نیرو به‌جای پد صرف شاک‌آبزوربر می‌شود. شاک‌آبزوربر را فقط در **انتهای بالا** بگذارید. در پایین، پد و فلوکنترل Meter-Out خودشان کار ضربه‌گیری را انجام می‌دهند.

**پیشنهاد:**

1. میز قطعه‌کار را **ارتفاع‌پذیر** کنید (پیچ یا جک پیچی) تا سطح چاپ قطعه با سطح کلیشه **هم‌تراز** شود. این روش استاندارد دستگاه‌های تامپو است.
2. یک **سنسور دوم Down** بگذارید: `X17 = Z_DOWN_PRINT`. در کد با پارامتر `M501` فعال می‌شود.
3. **زمان Dwell از لحظه‌ی تأیید سنسور Down شمرده شود،** نه از لحظه‌ی فرمان شیر. در کد همین کار انجام شده است. در غیر این صورت هر تغییر در فلوکنترل، زمان واقعی فشار را عوض می‌کند.
4. کورس ۲۰۰ برای یک سیکل تامپو **زیاد** است. هر ۱۰۰ میلی‌متر کورس اضافه، ۰.۳ تا ۰.۵ ثانیه به هر فرود و صعود اضافه می‌کند (۴ بار در هر سیکل). کورس مفید را با **استاپر مکانیکی بالا** کم کنید، یا کورس را ۱۰۰ تا ۱۲۵ بگیرید و ارتفاع کلی Z را با **اسلاید دستی تنظیم ارتفاع** تأمین کنید.

## ۱-۴ 🔴 ایمنی اپراتور: پدال به‌تنهایی کافی نیست

فرود پد با نیروی ۱ کیلونیوتن روی قطعه‌ای که دست اپراتور کنار آن است، طبق ISO 12100 یک **خطر له‌شدگی (Crushing)** است. پیشنهاد:

* **پرده‌ی نوری نوع ۲ یا ۴** (مثلاً مطابق EN 61496) جلوی ناحیه‌ی چاپ، یا گارد ثابت همراه با دریچه‌ی قطعه‌گذاری.
* **رله‌ی ایمنی** (مثل Pilz PNOZ s4 یا معادل آن) با: کانال دوگانه‌ی E-Stop، ورودی پرده‌ی نوری، و **کنتاکت تأخیری** برای Stop Category 1 (یعنی اول PLC محورها را ترمز می‌کند، بعد برق قدرت درایو قطع می‌شود).
* PLC استاندارد **مدار ایمنی نیست**. در این طرح، ورودی‌های `X10` (E-Stop OK) و `X16` (Guard OK) فقط **کنتاکت کمکی مانیتورینگ** رله‌ی ایمنی هستند. قطع واقعی را خود رله‌ی ایمنی انجام می‌دهد.
* هدف: حداقل **PL c** برای فرود پد و **PL d** برای E-Stop (بر اساس ارزیابی ریسک شما).

## ۱-۵ 🟠 محاسبات محور X و Y

<!-- output of tools/axis_sizing.py -->
```
Pulley: 24T HTD5M -> 120.0 mm/rev, pitch radius 19.10 mm
Resolution: 4000 p/rev -> 33.333 p/mm (0.0300 mm/pulse)

== X (pad carriage) ==
  avg speed 467 mm/s, PEAK speed 700 mm/s, accel 1.40 m/s^2 (t_acc 0.50 s)
  motor 350 rpm, pulse freq 23.3 kHz
  belt force 16.0 N, torque 0.31 N.m (x2 safety -> 0.62)
  inertia ratio load/rotor = 41:1  (with 1:3 gearbox -> 4.5:1)

== Y (closed cup) ==
  avg speed 267 mm/s, PEAK speed 400 mm/s, accel 0.80 m/s^2 (t_acc 0.50 s)
  motor 200 rpm, pulse freq 13.3 kHz
  belt force 64.0 N, torque 1.23 N.m (x2 safety -> 2.45)
  inertia ratio load/rotor = 16:1  (with 1:3 gearbox -> 1.8:1)
```

**نتیجه‌ها:**

* **گشتاور مشکل ندارد.** موتور 4 N·m در 350 rpm با 48V حدود 2.5 تا 3 N·m دارد، در حالی که نیاز حدود 0.6 N·m است.
* **مشکل اصلی اینرسی است.** نسبت ۴۱:۱ برای استپر، حتی کلوزلوپ، بالاست (توصیه معمول کمتر از ۱۰:۱ است). نتیجه‌اش لرزش انتهای حرکت، زمان نشست طولانی (Settling) و گاهی آلارم **Position Following Error** در CL57 است.
  * **پیشنهاد:** گیربکس خورشیدی **۱:۳** (NEMA24، بک‌لش کمتر از 15 arcmin). نسبت به 4.5:1 می‌رسد و سرعت موتور حدود 1050 rpm می‌شود که هنوز در ناحیه‌ی خوب گشتاور 48V است.
  * جایگزین ارزان‌تر: شیب شتاب نرم‌تر (S-Curve اگر در دسترس باشد، یا Accel حدود 400 تا 500 میلی‌ثانیه) و تنظیم دقیق **گین‌های CL57** با نرم‌افزار ProTuner.
* **سرعت پیک.** برای پیمودن ۷۰۰ میلی‌متر در ۱.۵ ثانیه با پروفایل ذوزنقه‌ای، سرعت پیک **حدود ۷۰۰ mm/s** لازم است، نه ۴۵۰. سقف سرعت در کد ۸۰۰ mm/s است.
* **رزولوشن.** CL57 را روی **4000 pulse/rev** تنظیم کنید. هر پالس ۰.۰۳ میلی‌متر است و فرکانس پیک حدود ۲۳ کیلوهرتز، که از ۲۰۰ کیلوهرتز PLC خیلی کمتر است و نویزپذیری کمتری هم دارد.
* **تسمه‌ی HTD5M عرض ۱۵** برای X و Y کافی است (نیروی کاری مجاز حدود ۴۰۰ نیوتن یا بیشتر). ولی در کورس ۷۰۰ و بار ۱۰ کیلو، **کشش اولیه‌ی تسمه** (حدود ۱۵۰ نیوتن) و **سختی آن** بر دقت توقف اثر دارد. یک **تنشنر پیچی** در یک سر کالسکه بگذارید، نه روی پولی.

## ۱-۶ 🟠 ولتاژ درایور و برق برگشتی

* بازه‌ی ورودی CL57 را در دیتاشیت مدل خودتان چک کنید (در بیشتر نسخه‌ها **24 تا 48 یا 50 VDC**). با تغذیه‌ی 48V حاشیه تقریباً صفر است. در ترمزگیری کالسکه‌ی ۱۰ کیلویی، ولتاژ باس با برق برگشتی بالا می‌رود و درایور خطای **Over-Voltage** می‌دهد. بعضی پاورهای سوئیچینگ هم در این حالت خاموش می‌شوند.
* **پیشنهاد:** پاور **36V** (از نظر گشتاور در این سرعت کافی است)، یا اگر 48V می‌ماند: **دیود سری و خازن ۴۷۰۰ µF/100V** بعد از پاور، یا ماژول **Regen Clamp**.
* پاور 48V/10A برای دو درایور CL57 کافی است (مصرف واقعی DC کمتر از جریان فاز است).

## ۱-۷ 🟠 هومینگ، سنسورها و لیمیت‌ها

* سنسور **NPN-NO** ایمن در برابر خرابی (Fail-Safe) نیست. اگر سیم قطع شود، DZRN هرگز سیگنال DOG نمی‌بیند و کالسکه با سرعت هومینگ به انتهای کورس می‌کوبد.
  * **پیشنهاد:** سنسور **NC** برای هوم، یا حداقل **لیمیت سخت‌افزاری NC در دو انتهای هر محور** (در این طرح `X6` و `X7`). این لیمیت‌ها در کد بلافاصله توقف می‌دهند و بهتر است سخت‌افزاری هم ENA درایور را قطع کنند.
  * **Timeout هومینگ** (`D547`) و **عقب‌نشینی خودکار** اگر کالسکه روی سنسور باشد، در کد پیاده شده است.
* سنسورهای **D-M9N** روی شیار جک ممکن است با لرزش جابه‌جا شوند. پیچ آن‌ها را با چسب رزوه ضعیف قفل کنید. **منطق Plausibility** هم در کد هست: اگر Up و Down هم‌زمان فعال باشند، آلارم A09 صادر می‌شود.
* آهنربای **کاپ مغناطیسی** اگر به سنسور Y_Home یا سنسورهای جک نزدیک باشد، روی سنسور مگنتی اثر می‌گذارد. دست‌کم ۵۰ میلی‌متر فاصله بگذارید.

## ۱-۸ 🟡 سیکل کاری: ترتیب فعلی حدود ۴۰٪ کندتر است

| مرحله | سیکل پیشنهادی شما (سریالی) | سیکل بهینه (این طرح) |
|---|---|---|
| جوهرزنی Y (رفت و برگشت) | 3.0 s | **هم‌زمان** با حرکت X و چاپ (گزینه‌ی `M500`) |
| X از X0 تا Pick | ≈1.0 s | **حذف شده.** موقعیت آماده (Ready) همان Pick است |
| Z پایین، Dwell1، Z بالا | ≈1.4 s | ≈1.4 s |
| X از Pick تا Print | ≈1.2 s | ≈1.2 s |
| Z پایین، Dwell2، Z بالا | ≈1.5 s | ≈1.5 s |
| X برگشت | ≈1.2 s (تا X0) | ≈1.2 s (تا Ready = Pick) |
| **جمع** | **≈9.3 s (حدود 390 قطعه در ساعت)** | **≈5.3 s (حدود 680 قطعه در ساعت)** |

* **X0 (هوم) نباید موقعیت آماده‌باش باشد.** بعد از هومینگ، کالسکه به موقعیت `X_READY` (پیش‌فرض برابر `X_PICK`) می‌رود و سیکل از همان‌جا شروع می‌شود.
* **هم‌پوشانی جوهرزنی (Overlap):** به‌محض اینکه پد تصویر را برداشت و بالا رفت، کاپ برای جوهرزنی تصویر بعدی حرکت می‌کند، در همان زمانی که پد به سمت قطعه می‌رود. اینترلاک ناحیه‌ای (Zone) در کد تضمین می‌کند که:
  * Z فقط وقتی در ناحیه‌ی کلیشه پایین می‌آید که کاپ در موقعیت Park و متوقف باشد.
  * Y فقط وقتی حرکت می‌کند که پد بالا باشد، **یا** پد بیرون از ناحیه‌ی کلیشه باشد.
* ⚠️ Overlap زمان باز ماندن تصویر در هوا را بیشتر می‌کند (حدود ۳ تا ۴ ثانیه). برای رنگ‌های زودخشک، **تینر کندکننده (Retarder)** بزنید یا Overlap را خاموش کنید. پارامتر `Flash-off (D542)` زمان مکث بین تمام شدن جوهرزنی و فرود پد را کنترل می‌کند.

## ۱-۹ 🟡 محور Y (کاپ بسته)

* کاپ باید **شناور (Floating)** به واگن HGR15 وصل شود: پین راهنما با لقی عمودی، یا اتصال فنری. کوپل صلب یعنی رینگ سرامیکی یا تیغه یکنواخت روی کلیشه نمی‌نشیند، رنگ نشت می‌کند و رینگ زود ساییده می‌شود.
* در شروع حرکت کاپ پدیده‌ی **چسبش و لغزش (Stick-Slip)** رخ می‌دهد، چون اصطکاک ایستایی بالاست. شتاب اولیه را کم کنید (`D532` ≥ 400 ms) و فرکانس شروع `D1352` را پایین نگه دارید.
* **سرعت رفت و برگشت جدا** (`D527` و `D528`): معمولاً برگشت که عمل Doctoring نهایی است، کندتر تنظیم می‌شود تا تیغه‌کشی تمیزتر باشد.
* وقتی ماشین بیکار است، اگر کاپ روی تصویر پارک شود، رنگ داخل حکاکی خشک نمی‌شود. اگر مکانیک اجازه می‌دهد، `Y_PARK` را روی تصویر بگذارید و ترتیب «رفت و برگشت» را متناسب با آن عوض کنید.

## ۱-۱۰ 🟡 HMI و Modbus

* اگر در حالی که دکمه‌ی Jog روی HMI نگه داشته شده کابل RS-485 قطع شود، بیت در PLC ممکن است ON بماند.
  * **در کد:** **Heartbeat** اضافه شده. HMI هر ۰.۵ ثانیه `D60` را یکی زیاد می‌کند. اگر ۲ ثانیه تغییر نکند، همه‌ی بیت‌های `M100` تا `M119` پاک می‌شوند و آلارم A14 می‌آید.
  * Jog در حالت «هوم نشده» به حداکثر ۵۰ میلی‌متر در هر فشار و سرعت Creep محدود است. در حالت هوم‌شده به Soft-Limit محدود است.
  * برای تعمیرات، **دکمه‌ی فیزیکی Jog روی تابلو** بهتر است (یا Enable Switch سه‌حالته).
* دکمه‌های فرمان (Start، Home، Go-To) از نوع **Set ON** باشند. PLC بعد از یک اسکن خودش آن‌ها را Reset می‌کند.

## ۱-۱۱ نکات تکمیلی

* **تمیزکننده‌ی پد (Pad Cleaning Tape):** برای چاپ پیوسته تقریباً ضروری است. یک خروجی رزرو کنید (نیاز به ماژول توسعه‌ی DVP08SN11T سمت راست دارد).
* **سنسور حضور قطعه:** جلوی چاپ روی فیکسچر خالی را می‌گیرد. این هم ورودی توسعه لازم دارد.
* **I/O تقریباً پر است** (۱۶ ورودی و ۱۲ خروجی، همه استفاده شده). از اول یک ماژول **DVP16SP11T** (۸ ورودی و ۸ خروجی) در نظر بگیرید.
* **رسپی (Recipe):** HMI DOP-107BV قابلیت Recipe دارد. موقعیت‌ها، سرعت‌ها و Dwellها را برای هر محصول جدا ذخیره کنید (بخش ۵ را ببینید).

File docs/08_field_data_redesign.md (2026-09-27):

# ۸. داده‌های دستگاه موجود و طراحی از صفر

> این بخش بر اساس عکس‌ها و اندازه‌گیری‌های دستگاه فعلی نوشته شده است (مهر ۱۴۰۵).
> **هرجا با بخش‌های ۱ تا ۷ تناقض دارد، این بخش معتبر است.** بخش‌های قبلی بر پایه‌ی اطلاعات اولیه نوشته شده بودند و پس از تأیید انتخاب‌ها به‌روز می‌شوند.
> عکس‌ها: پوشه‌ی [`field_photos/`](field_photos/)

## ۸-۱ دستگاه فعلی چه دارد؟

| محور | قطعه | کورس | زمان | محاسبه (فشار ۵.۱ بار) |
|---|---|---|---|---|
| **Z** (پد) | جک **SC63×150** با دو میله‌ی راهنمای بیرونی | ۱۴۰ mm | حدود ۲ ثانیه پایین و بالا، با مکث ۰.۵ ثانیه | فشار رو به پایین **≈ ۱۵۹۰ نیوتن (۱۶۰ کیلوگرم)** |
| **X** (کالسکه‌ی پد) | جک **SC40×500** روی **دو شفت گرد بزرگ با بوش گریس‌خور** | ۴۷۰ mm | رفت ۱.۱۸ ثانیه، برگشت ۱.۵۷ ثانیه | جرم متحرک **۱۳ تا ۱۴ کیلوگرم** |
| **Y** (کاپ) | موتور گیربکس‌دار زاویه‌ای **Kormas** 24VDC، 100 وات، ۲۳۵ دور، ۱:۱۵، انکودر مغناطیسی، کنترل PWM. انتقال با **پولی حدود ۶۶ میلی‌متر و تسمه‌ی تایم باز عرض ۲۰ میلی‌متر** | ۳۷۰ mm | رفت و برگشت ۲.۶۱ ثانیه | حداکثر سرعت موتور ≈ ۸۱۰ mm/s (الان حدود ۳۵٪ آن استفاده می‌شود). نیروی نامی ≈ **۹۰ نیوتن** |
| پد | کد **3016**، شیروانی، ۱۹.۵×۱۴×۸ cm | – | مکث روی کلیشه و قطعه **≈ ۰.۵ ثانیه** | وزن ۱.۸ کیلوگرم |
| کلیشه | – | ۵۸۰×۲۰۰ mm | – | – |
| میز قطعه | **ثابت**. اپراتور قطعه را با دست می‌چرخاند (مثلاً سه چاپ در سه جهت) | – | – | – |
| کنترل | PLC **Delta DVP-14SS2**، HMI دلتا، رله‌های Finder، پدال | – | – | – |
| **کل سیکل** | – | – | **۱۰.۵ ثانیه** | **≈ ۳۴۰ چاپ در ساعت** |

> «فشار ۵.۱ kPa» در واقع **۵.۱ بار** است.
>
> **اصلاح:** در نسخه‌ی قبلی این سند انتقال محور Y «چرخ‌دنده و شانه» نوشته شده بود. عکس‌های نزدیک نشان می‌دهد **تسمه‌ی تایم** است. دندانه‌های تسمه در عکس اول شبیه شانه دیده می‌شدند.

### زمان سیکل کجا می‌رود؟ (همه‌ی حرکت‌ها پشت سر هم)

```
Y جوهرزنی     ██████████████               2.6 s
Z روی کلیشه                 ██████████     2.0 s
X رفت                                  ██████  1.2 s
Z روی قطعه                                   ██████████  2.0 s
X برگشت                                                ████████  1.6 s
فاصله‌ها ≈ 1.1 s                                        جمع ≈ 10.5 s
```

**بزرگ‌ترین اتلاف‌ها:** Z با حدود ۴ ثانیه، و Y با ۲.۶ ثانیه که پشت سر هم انجام می‌شود.

## ۸-۲ درس‌های مهم از دستگاه فعلی

| موضوع | طرح اولیه (Gemini) | واقعیت | نتیجه |
|---|---|---|---|
| نیروی Z | MGPM25 ≈ ۲۵۰ نیوتن | SC63 ≈ **۱۶۰۰ نیوتن** با پد بزرگ ۱۹.۵×۱۴ | **Z باید حداقل Ø63 باشد** |
| کورس X | ۷۰۰ mm | فعلی ۴۷۰ و **هدف جدید ۶۲۰ mm** | – |
| جرم X | ۸ تا ۱۰ kg | **۱۳ تا ۱۴ kg** | محاسبه با ۱۴ کیلو انجام شد |
| انتقال Y | تسمه ۱۵ mm | تسمه **۲۰ mm** و موتور DC ≈ ۹۰ N | تسمه‌ی Y جواب داده است و می‌ماند |

## ۸-۳ طراحی پیشنهادی از صفر

### محور Z: پنوماتیک بماند، ولی سریع‌تر

| مورد | پیشنهاد | دلیل |
|---|---|---|
| جک | **Ø63**، کورس **۱۰۰ mm**، با **راهنما** (مثل فعلی)، مگنت‌دار | زور ثابت‌شده برای پد 3016. کورس کمتر یعنی سریع‌تر |
| تنظیم ارتفاع | **اسلاید دستی** (پیچی) زیر مجموعه‌ی Z | ارتفاع را با اسلاید تنظیم کنید، نه با کورس جک |
| شیر | 5/2 **سایز 3/8**، **نزدیک جک** | عبور باد بیشتر |
| سرعت | دو **شیر تخلیه‌ی سریع** (Quick Exhaust) به همراه فلوکنترل | Z تقریباً دو برابر سریع‌تر |
| فشار چاپ | **رگولاتور جدا** برای Z، به همراه گیج | فشار چاپ ثابت |
| ایمنی | شیر پایلوت‌چک | پد در قطع باد نمی‌افتد |
| سنسورها | **بالا**، **ارتفاع امن** و **پایین** | برای هم‌پوشانی حرکت با X |

**هدف:** در هر ایستگاه ≈ ۰.۳۵ ثانیه پایین، ۰.۵ ثانیه مکث و ۰.۳۵ ثانیه بالا، یعنی **≈ ۱.۲ ثانیه** به‌جای ۲ ثانیه.

### محور X: موتور برقی به‌جای جک

**محاسبه با جرم ۱۴ کیلو:**

| حرکت | سرعت پیک | شتاب | نیروی لازم | گشتاور لازم روی موتور (گیربکس ۱:۳، پولی ۲۴ دندانه) | دور موتور |
|---|---|---|---|---|---|
| ۵۰۰ mm در ۰.۹ ثانیه | 833 mm/s | 2.8 m/s² | ≈ 50 N | **≈ 0.36 N·m** | ≈ 1250 rpm |
| ۶۲۰ mm در ۱.۱ ثانیه | 845 mm/s | 2.3 m/s² | ≈ 43 N | **≈ 0.31 N·m** | ≈ 1270 rpm |

استپر کلوزلوپ ۴ N·m در ۱۲۵۰ دور با ۴۸ ولت حدود ۱.۲ تا ۱.۵ N·m گشتاور دارد، یعنی **حدود ۳ تا ۴ برابر حاشیه**. نسبت اینرسی با گیربکس ۱:۳ برابر **≈ ۶:۱** است که خوب است.

| مورد | پیشنهاد |
|---|---|
| موتور | **استپر کلوزلوپ NEMA24، ۴ N·m (۴۰ kg·cm)**، به همراه درایور کلوزلوپ ۴۸ ولت |
| گیربکس | خورشیدی **۱:۳** |
| انتقال | تسمه‌ی **HTD5M عرض ۲۵ mm مغزی فولادی**، پولی ۲۴ دندانه، تنشنر پیچی |
| راهنما | **دو ریل HGR20** با چهار واگن (پیشنهاد اول). **جایگزین:** همان **دو شفت Ø45** فعلی که کاملاً محکم است، با **بوش پلیمری خشک** (مثل igus drylin) یا بوش برنزی به‌جای بوش گریسی فعلی. بوش گریسی کثیفی و رنگ جذب می‌کند |
| کورس | ۶۲۰ mm |

*گزینه‌ی ارتقا:* سروو AC دلتا ۴۰۰ وات (ASDA-B3). سریع‌تر و نرم‌تر است، ولی گران‌تر. برای این بار، استپر کافی است.

### محور Y: همان تسمه، موتور هم‌نوع X

| مورد | پیشنهاد |
|---|---|
| موتور | **استپر کلوزلوپ NEMA24 ۴ N·m** (همان موتور X، مستقیم و بدون گیربکس) |
| انتقال | همان **تسمه‌ی ۲۰ mm** و ساختار فعلی |
| پولی | **۲۴ دندانه HTD5M** (قطر ≈ ۳۸ mm) به‌جای ۶۶ mm. نیرو تقریباً دو برابر می‌شود (≈ ۱۵۰ تا ۲۰۰ N) و دور موتور در سرعت ۴۵۰ mm/s حدود ۲۲۵ rpm می‌شود، که در این دور استپر تقریباً تمام گشتاورش را دارد |

موتور DC فعلی حدود ۹۰ نیوتن نیرو دارد. استپر با پولی کوچک‌تر **حدود دو برابر** آن را می‌دهد.

> **نوع تسمه (اندازه‌گیری‌شده):** ۲۰ دندانه در ۱۰ سانت، یعنی **گام ۵ mm** و عرض ۲۰ mm. پولی فعلی ۶۶ mm حدود ۴۰ دندانه دارد. هنگام خرید پولی ۲۴ دندانه، **شکل دندانه** را هم با تسمه تطبیق دهید: گرد (**HTD5M**) یا ذوزنقه‌ای (**T5 / AT5**). ساده‌ترین راه این است که یک تکه تسمه یا پولی فعلی را به فروشنده نشان دهید.

**کدام محور موتور قوی‌تر لازم دارد؟** برخلاف انتظار، **Y**. محور X با گیربکس ۱:۳ روی موتور فقط ≈ ۰.۴ N·m بار دارد. محور Y مستقیم است و اصطکاک و چسبندگی کاپ روی کلیشه زیاد است: ۶۰ تا ۹۰ N × شعاع پولی ۱۹ mm ≈ **۱.۱ تا ۱.۷ N·m**، که با ضریب اطمینان ۲ به **۲.۳ تا ۳.۴ N·m** می‌رسد. پس هر دو محور همان موتور **۴ N·m** را می‌گیرند.

### کنترل و ایمنی

| قطعه | پیشنهاد |
|---|---|
| PLC | **Delta DVP-28SV11T2**، به همراه ماژول **DVP16SP11T** |
| HMI | **DOP-107BV** |
| ایمنی | رله‌ی ایمنی، E-Stop و **پرده‌ی نوری جلوی محل چاپ** |

> ⚠️ **ایمنی در این دستگاه جدی‌تر است:** اپراتور بعد از **هر** چاپ دستش را برای چرخاندن قطعه زیر پد می‌برد، و پد با **۱۶۰ کیلوگرم** فرود می‌آید. پرده‌ی نوری باید طوری نصب شود که اگر دست در محل چاپ باشد، **پد پایین نیاید**.

## ۸-۴ سیکل جدید

### حالت عادی (پدال برای هر چاپ)

| مرحله | فعلی | جدید |
|---|---:|---:|
| Z روی کلیشه | 2.0 s | 1.2 s |
| X رفت | 1.2 s | 0.8 s (با هم‌پوشانی) |
| Z روی قطعه | 2.0 s | 1.2 s |
| X برگشت | 1.6 s | 0.8 s (با هم‌پوشانی) |
| Y جوهرزنی | 2.6 s (جدا) | **0** (هم‌زمان با X) |
| فاصله‌ها | 1.1 s | 0.4 s |
| **جمع** | **10.5 s ≈ 340 چاپ در ساعت** | **≈ 4.4 s ≈ 800 چاپ در ساعت** (برآورد محافظه‌کارانه: ۵ تا ۵.۵ ثانیه) |

### پیشنهاد مخصوص کار شما: برداشت زودتر

چون اپراتور بین چاپ‌ها قطعه را می‌چرخاند، دستگاه در همان زمان می‌تواند **کار بعدی را آماده کند**:

1. بعد از چاپ، X برمی‌گردد، پد رنگ را از کلیشه برمی‌دارد و **بالای کلیشه منتظر می‌ماند**.
2. اپراتور قطعه را می‌چرخاند و پدال را می‌زند.
3. **فقط** X رفت و Z روی قطعه انجام می‌شود، یعنی **≈ ۲ ثانیه** بعد از پدال چاپ انجام شده است.

⚠️ رنگ روی پد نباید زیاد منتظر بماند، چون خشک می‌شود. پارامتر «حداکثر زمان انتظار» روی نمایشگر تعریف می‌شود. اگر پدال دیر زده شود، پد یک بار روی کلیشه برمی‌گردد و دوباره رنگ برمی‌دارد.

## ۸-۵ داده‌های تکمیلی

* تسمه‌ی Y: گام ۵ mm، عرض ۲۰ mm.
* شفت‌های X: دو شفت Ø45 mm.

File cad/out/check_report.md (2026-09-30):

# گزارش بررسی مدل سه‌بعدی (خودکار)

تاریخ ساخت: 2026-09-30 20:00 — تعداد قطعات در مدل: **212**

## ۱. تداخل قطعات ثابت (مدل‌سازی)

✅ هیچ دو قطعه‌ی ثابتی در هم نرفته‌اند (فقط تماس سطحی، مثل جوش و پیچ).

## ۲. تداخل قطعات متحرک در موقعیت‌های مختلف

«تماس عمدی» یعنی تسمه داخل گیره‌اش، شافت داخل جک، یا پد در حال فشردن روی کلیشه یا قطعه.

| حالت | نتیجه |
|---|---|
| X=0 (خانه)، Z بالا، کاپ روی تصویر | ✅ بدون برخورد (تماس‌های عمدی: 3) |
| X=50 برداشت، Z پایین، کاپ عقب | ✅ بدون برخورد (تماس‌های عمدی: 4) |
| X=50 برداشت، Z بالا، کاپ روی تصویر (انتظار برداشت زودتر) | ✅ بدون برخورد (تماس‌های عمدی: 3) |
| X=280 عبور پد از پنجره‌ی جلو، Z بالا، کاپ در حال حرکت | ✅ بدون برخورد (تماس‌های عمدی: 3) |
| X=495 چاپ دیسک Ø1000، Z پایین | ✅ بدون برخورد (تماس‌های عمدی: 5) |
| X=750 بیشترین دسترسی (440 mm بیرون)، Z بالا | ✅ بدون برخورد (تماس‌های عمدی: 3) |
| X=750 بیشترین دسترسی، Z پایین | ✅ بدون برخورد (تماس‌های عمدی: 4) |

## ۳. فاصله‌های کلیدی

| فاصله | mm |
|---|---:|
| پد (بالا) تا بازوی کاپ، وقتی پد منتظر روی کلیشه است | 33.0 |
| پد (بالا) تا بالای کاپ | 50.0 |
| پد (پایین، برداشت) تا کاپ عقب‌رفته | 234.2 |
| صفحه‌ی کناری هد Z (پایین) تا تیر ریل | 68.0 |
| هد Z تا ستون‌های جلو هنگام عبور از پنجره | 50.0 |
| پد (بالا) تا لبه‌ی پایین پنجره‌ی جلو | 20.0 |
| هد Z در بیشترین دسترسی تا عرضی سر تیرها | 49.2 |
| فضای آزاد بالای دیسک تا زیر تیرهای X (جای دست) | 272.0 |
| لبه‌ی دیسک تا بدنه‌ی دستگاه | 60.0 |

## ۴. سفتی سازه (نیروی چاپ واکنش به بالا روی ریل‌ها)

| مورد | خیز mm |
|---|---:|
| خیز تیرهای X در برداشت (بین دو تکیه‌گاه)، 1590 N | 0.004 |
| خیز سر یک‌سرآزاد تیرهای X در چاپ دیسک Ø1000 (215 mm بیرون از ستون جلو) | 0.014 |
| خیز سر یک‌سرآزاد تیرهای X در بیشترین دسترسی (470 mm بیرون از ستون جلو) | 0.090 |

خیز زیر ۰.۵ mm در برابر فشردگی چند میلی‌متری پد ناچیز است و از چاپی به چاپ دیگر ثابت می‌ماند.

### اگر میز دیسک به دستگاه پیچ نشود (واژگونی)

وزن بدنه‌ی دستگاه ≈ **3419 N**، مرکز جرم در X = 377 mm. نیروی چاپ رو به بالا جلوی دستگاه را بلند می‌کند:

| محل چاپ X | گشتاور بلندکننده N·m | گشتاور وزن N·m | نتیجه |
|---:|---:|---:|---|
| 785 | 1200 | 1186 | ❌ جلوی دستگاه بلند می‌شود |
| 1040 | 1606 | 1186 | ❌ جلوی دستگاه بلند می‌شود |

**به همین دلیل میز دیسک با ۴ لوله‌ی اتصال به بدنه پیچ می‌شود.** نیروی چاپ داخل فولاد بسته می‌شود و دستگاه هرگز بلند نمی‌شود. یا باید دستگاه را با رول‌بولت به زمین بست.

## ۵. جرم‌ها

| مورد | kg |
|---|---:|
| کل دستگاه (بدون تابلو و میز دیسک) | 320.5 |
| میز دیسک | 138.1 |
| اسکلت لوله‌ای | 202.5 |
| متحرک X (کالسکه + هد Z) | 22.4 |
| متحرک Z | 10.7 |
| متحرک کاپ | 2.4 |

## ۶. بررسی دوباره‌ی موتور X با جرم واقعی مدل

* جرم متحرک X از مدل: **22.4 kg** (در محاسبه‌ی اولیه ۱۴ kg فرض شده بود).
* نیروی لازم در شتاب ۲.۸ m/s²: **82 N** → گشتاور روی موتور با گیربکس ۱:۳ و پولی ۲۴ دندانه: **0.58 N·m**.
* گشتاور موجود استپر ۴ N·m در ≈۱۲۵۰ rpm: ۱.۲ تا ۱.۵ N·m → حاشیه‌ی **2.1 تا 2.6 برابر** ✅
* نسبت اینرسی بار به روتور: **≈ 8.7 : 1** (برای استپر کلوزلوپ تا ۱۰:۱ مناسب است).

## ۷. نیروی تسمه‌ی X خارج از مرکز کالسکه

* مرکز جرم بخش متحرک X در Y = **-2 mm** است. خط تسمه در Y = **100 mm** است، پس فاصله **102 mm** است.
* گشتاور چرخشی (دور محور عمودی) در بیشترین شتاب: **8.4 N·m**.
* این گشتاور به‌صورت نیروی جانبی روی واگن‌ها می‌نشیند: **≈ 30 N برای هر واگن**. ظرفیت هر واگن HGH20CA حدود **17,750 N** است، یعنی کمتر از **0.2٪** ظرفیت ✅
* در طرح قبلی که تسمه بیرون بود (Y = 215)، همین عدد 64 N بود. با آوردن تسمه به داخل، نصف شد.

## ۸. سنسورهای القایی Z: کی روشن‌اند؟ (از روی هندسه‌ی مدل)

پد از 0 (کاملاً بالا) تا 100 mm (ته کورس) پایین می‌رود. هر سنسور وقتی روشن است که تسمه‌ی آهنی جلویش باشد.

| سنسور | روشن در پایین‌رفتن | لازم برای برنامه‌ی PLC |
|---|---|---|
| X2 بالا | از 0.0 تا 2.0 mm | کمتر از 2 mm |
| X20 ارتفاع امن | از 0.0 تا 32.0 mm | از 0 تا 32 mm |
| X3 پایین | از 94.5 تا 100.0 mm | از 94.5 mm به بعد |

حدود واقعی کمی (حدود ۱ تا ۲ mm) با این عددها فرق دارد، چون سطح حس سنسور ۱۲ mm قطر دارد. هنگام راه‌اندازی، هر سنسور را با شیار براکت طوری تنظیم کنید که چراغ آن دقیقاً در همین نقطه‌ها روشن و خاموش شود.

## ۹. ریل‌های X

* طول هر ریل HGR20: **1060 mm** (استاندارد HIWIN: گام سوراخ ۶۰، از هر سر ۲۰ mm).
* کورس X: 750 mm. فاصله‌ی اطمینان ریل بعد از واگن‌ها: **46 mm** در ابتدای کورس و **38 mm** در انتها (برای رد شدن از لیمیت سوئیچ و ترمز).
* بار چاپ روی هر واگن: **398 N** (نیرو رو به بالا). ظرفیت ایستای هر واگن HGH20CA: 27,760 N، یعنی ضریب اطمینان **70**. حتی با ضربه‌ی دو برابر، ضریب **35** است (HIWIN برای ضربه ۳ تا ۵ را کافی می‌داند).
* واگن‌های سری HG در هر چهار جهت (پایین، بالا، چپ و راست) ظرفیت برابر دارند، پس کشیده شدن رو به بالا مشکلی ندارد.
* در حین حرکت X، پد بالاست (قانون «پد روی سطح = X ساکن»)، پس واگن‌ها در حرکت فقط وزن کالسکه را می‌برند.

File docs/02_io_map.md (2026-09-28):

# ۲. جدول تخصیص آدرس‌ها (I/O، M، D، T) — نسخه‌ی ۲ (طرح جدید)

PLC: **DVP-28SV11T2** (ورودی X0 تا X17 و خروجی Y0 تا Y13) + ماژول توسعه‌ی **DVP16SP11T** (ورودی X20 تا X27 و خروجی Y20 تا Y27).
ورودی‌ها به‌صورت **Sink** سیم‌بندی می‌شوند (سنسورها NPN هستند و S/S به +24V وصل است).

## ۲-۱ ورودی‌های دیجیتال (X)

| آدرس | نام | نوع و سیم‌بندی | منطق | توضیح |
|---|---|---|---|---|
| X0 | X_HOME | القایی NPN M18 | 1 = روی DOG | DOG دستور DZRN محور X |
| X1 | Y_HOME | القایی NPN M18 | 1 = روی DOG | DOG دستور DZRN محور Y |
| X2 | Z_UP | سنسور القایی M12 روی براکت کالسکه، رو به تسمه‌ی آهنی هد Z | 1 = پد کاملاً بالا | |
| X3 | Z_DOWN | سنسور القایی M12 (همان براکت) | 1 = پد روی کلیشه یا قطعه فشرده شده | شروع Dwell |
| X4 | X_DRV_OK | خروجی ALM درایور | **1 = سالم** | قطع سیم هم فالت دیده می‌شود |
| X5 | Y_DRV_OK | ALM درایور | **1 = سالم** | |
| X6 | X_OT_OK | دو لیمیت NC سری | **1 = سالم** | Over-travel سخت‌افزاری X |
| X7 | Y_OT_OK | دو لیمیت NC سری | **1 = سالم** | |
| X10 | ESTOP_OK | کنتاکت کمکی رله‌ی ایمنی | **1 = سالم** | فقط مانیتورینگ |
| X11 | PEDAL | پدال | لبه‌ی بالارونده | در مرحله‌های S5 تا S70 ذخیره می‌شود (M94) |
| X12 | START_PB | شستی سبز NO | 1 = فشرده | |
| X13 | STOP_PB | شستی قرمز **NC** | **0 = فشرده** | توقف در پایان سیکل |
| X14 | RESET_PB | شستی آبی NO | لبه | |
| X15 | AIR_OK | پرشر سوئیچ | 1 = فشار کافی | |
| X16 | GUARD_OK | پرده‌ی نوری (از رله‌ی ایمنی) | **1 = سالم** | شرط فرود Z در ایستگاه چاپ |
| X17 | Z_DOWN_PRINT | سنسور مگنتی (اختیاری) | 1 = پد روی قطعه | با `M501` فعال می‌شود |
| **X20** | **Z_SAFE** | **سنسور القایی M12 سوم (همان براکت)** | **ناحیه‌ای:** از کاملاً بالا تا ارتفاع امن پیوسته 1 است (طول تسمه‌ی آهنی = ناحیه) | **ارتفاع امن:** جایی که پد از کاپ، لبه‌ی کلیشه و فیکسچر بالاتر است |
| X21–X27 | رزرو | – | – | حضور قطعه، نوار تمیزکننده و … |

## ۲-۲ خروجی‌های دیجیتال (Y)

| آدرس | نام | به کجا وصل می‌شود | توضیح |
|---|---|---|---|
| Y0 / Y1 | X_PUL / X_DIR | درایور X | پالس CH0 |
| Y2 / Y3 | Y_PUL / Y_DIR | درایور Y | پالس CH1 |
| Y4 | SOL_Z_DOWN | بوبین A شیر 5/2 سایز 3/8 **از طریق کنتاکت NO رله‌ی ایمنی** | پد پایین |
| Y5 | SOL_Z_UP | بوبین B (24V معمولی) | `Y5 = NOT Y4` |
| Y6 / Y7 | X_ENABLE / Y_ENABLE | رله‌ی واسط به ENA درایورها | 1 = فعال |
| Y10 | LAMP_GREEN | چراغ برج | ثابت = تولید، چشمک = آماده |
| Y11 | LAMP_AMBER | چراغ برج | هوم نشده، حالت دستی، یا بچ تمام شده |
| Y12 | LAMP_RED | چراغ و بوق | آلارم |
| Y13 | AIR_MAIN | شیر Soft-Start | در E-Stop خاموش **نمی‌شود** |
| Y20–Y27 | رزرو | ماژول توسعه | |

## ۲-۳ رله‌های کمکی (M) – غیرماندگار

| آدرس | نام | توضیح |
|---|---|---|
| M20 | SAFE_OK | E-Stop، هوا، درایورها و لیمیت‌ها سالم‌اند و آلارمی نیست |
| M21 | ANY_ALARM | `D50 ≠ 0` یا `D51 ≠ 0` |
| M22 / M23 / M24 | X_HOMED / Y_HOMED / ALL_HOMED | |
| M25 | Z_UP_OK | پد کاملاً بالا و نشسته (برای هومینگ) |
| **M26** | **Z_ABOVE_SAFE** | **پد بالاتر از ارتفاع امن است.** برابر X20، به شرطی که X3 و X17 خاموش باشند. قطع سیم یا شل شدن تسمه‌ی آهنی = خاموش = X حرکت نمی‌کند |
| M28 / M29 | STOP_POSLOSS / STOP_IMMEDIATE | کلاس‌های توقف |
| M30 | X_IN_ZONE | پد بالای ناحیه‌ی کلیشه است |
| M31 / M32 / M34 | X_AT_PICK / X_AT_PRINT / X_AT_PARK | در موقعیت و متوقف |
| M33 / M35 | Y_AT_PARK / Y_AT_END | |
| M36 | ENA_RESET_PULSE | |
| M38 | MANUAL_ENABLE | |
| **M40** | **PERMIT_X** | `M26` (بالای ارتفاع امن) و سنسورهای Down خاموش |
| **M41** | **PERMIT_Z_DOWN** | [(Pick یا پنجره‌ی زودهنگام Pick) و کاپ Park] یا [(Print یا پنجره‌ی زودهنگام Print) و پرده‌ی نوری سالم] |
| **M42** | **PERMIT_Y** | `M26` یا X بیرون از ناحیه‌ی کلیشه |
| M45 / M46 | X_REQ_POS / X_REQ_JOG | |
| M47 / M48 | Y_REQ_POS / Y_REQ_JOG | |
| M50 / M52 | X_RUN / Y_RUN | کنتاکت DDRVA |
| M54 / M55 | X_DZRN / Y_DZRN | |
| M56 / M57 | Y_HOME_DONE / X_HOME_DONE | |
| M58 / M59 | X_CH_IDLE / Y_CH_IDLE | کانال دست‌کم یک اسکن آزاد بوده است |
| M60 / M61 | Z_DOWN_AUTO / Z_DOWN_MAN | |
| M62 | Z_DOWN_OK | X3 یا (X17 و M501) |
| **M63** | **EARLY_PICK_WINDOW** | M507 و مقصد X = Pick و فاصله‌ی باقی‌مانده ≤ D550 و کلیشه جوهر خورده |
| **M64** | **EARLY_PRINT_WINDOW** | M507 و مقصد X = Print و فاصله‌ی باقی‌مانده ≤ D550 |
| M70 تا M87 | خروجی‌های DZCP | M71=Pick، M74=Print، M77=Park، M80=Zone، M83=Y Park، M86=Y End |
| M90 / M91 | AUTO_ACTIVE / STOP_REQ | |
| M92 | INK_READY | تصویر روی کلیشه جوهر خورده است |
| **M93** | **PAD_LOADED** | پد رنگ را برداشته و منتظر چاپ است |
| **M94** | **PRINT_REQUEST** | پدال ذخیره‌شده |
| M95 | BATCH_DONE | |
| **M96 / M97** | **X_TARGET_PICK / X_TARGET_PRINT** | مقصد فعلی X |
| **M99** | PRINT_DONE_PULSE | شروع دوباره‌ی تایمر فاصله‌ی چاپ‌ها |
| M100 تا M119 | فرمان‌های HMI | بخش ۵ |
| M120 | MODE_AUTO | |
| **M130 / M131** | LOGIN_REQ / LOGOUT_REQ | از HMI |
| **M132 / M133** | LOGGED_IN / LOGIN_FAIL | |
| M134 / M135 / M136 / M137 | SHIFT_CHANGE / LOGIN_EDGE / LOGIN_OK / NEED_LOGIN | |
| M200 تا **M220** | آلارم‌های A01 تا **A21** | M200 تا M215 در `D50`، M216 تا M220 در `D51` (A17 فرود حین حرکت، A18 منطقه‌ی ممنوع، A19 داخل منطقه، A20 خطای PLC، A21 مرحله‌ی نامعتبر) |
| M140 / M141 | RESTORE_DEFAULTS / SAFE_RESET | از HMI |
| M150 تا M162 | دلیل‌های «چرا کار نمی‌کند» | در `D680` |

### M ماندگار (M500 به بعد) – گزینه‌ها

| آدرس | نام | پیش‌فرض | توضیح |
|---|---|---|---|
| M500 | PARALLEL_INKING | **1** | جوهرزنی هم‌زمان با حرکت X |
| M501 | Z_DOWN2_SENSOR | 0 | سنسور Down دوم روی X17 |
| M502 | CONTINUOUS | – | **از روی D554 = 2 محاسبه می‌شود** (دیگر از HMI نوشته نمی‌شود) |
| M503 | DRY_RUN | 0 | بدون فرود Z |
| M504 | BATCH_STOP | 0 | |
| M505 | HMI_WATCHDOG | 1 | |
| **M506** | **PRE_PICK** | 0 | برداشت زودتر و انتظار بالای کلیشه. بعد از راه‌اندازی روشن شود |
| **M507** | **EARLY_Z_DESCENT** | 0 | فرود زودهنگام Z (هم‌پوشانی). بعد از تنظیم D550 روشن شود |

### M ویژه‌ی سیستمی SV2 (با دفترچه تطبیق دهید)

| آدرس | کاربرد |
|---|---|
| M1000 / M1002 / M1013 | همیشه ON / اولین اسکن / کلاک ۱ ثانیه |
| M1029 / M1030 | پایان پالس CH0 / CH1 |
| M1078 / M1104 | توقف فوری پالس CH0 / CH1 |
| M1336 / M1337 | در حال ارسال پالس CH0 / CH1 |

## ۲-۴ رجیسترها (D)

### کاری

| آدرس | نام | واحد |
|---|---|---|
| D0 / D1 / D2 / D3 / D4 | AUTO / INK / HOME / X_HOME / Y_HOME step | – |
| D9 | MACHINE_STATE | ۰ هوم نشده، ۱ هومینگ، ۲ آماده، ۳ اتومات، ۴ در حال توقف، ۵ آلارم |
| D10:11 / D12:13 | X target / freq | پالس / Hz |
| D14:15 / D16:17 | Y target / freq | پالس / Hz |
| D18 تا D25 | سرعت‌های هوم و Creep | Hz |
| **D30:31 / D34:35** | **X_POS / Y_POS** | 0.1 mm |
| D40 تا D49 | موقت محاسبات | – |
| D50 / **D51** | ALARM_WORD 1 / 2 | bit |
| D60 / D61 | HMI heartbeat | – |
| D70 تا D89 | حدود DZCP | 0.1 mm |
| **D90:91** | **X_DIST_TO_GO** | 0.1 mm |
| D98 | مرحله‌ی قبلی | – |
| D200:201 / D202 | X command pos / speed | 0.1 mm / mm/s |
| D204:205 / D206 | Y command pos / speed | 0.1 mm / mm/s |

### پارامترها (ماندگار)

| آدرس | پارامتر | واحد | پیش‌فرض | بازه‌ی HMI |
|---|---|---|---|---|
| D500:501 | X_PICK_POS | 0.1 mm | 1000 | 0 تا Soft Max |
| D502:503 | X_PRINT_POS | 0.1 mm | 5500 | 0 تا Soft Max |
| D504:505 | X_PARK_POS (بعد از هومینگ) | 0.1 mm | 1000 | |
| D506:507 | X_SOFT_MAX | 0.1 mm | 6150 | ≤ 6200 |
| D508:509 / D510:511 | ناحیه‌ی کلیشه Min / Max | 0.1 mm | 0 / 2500 | |
| D512:513 / D514:515 | Y_PARK / Y_END | 0.1 mm | 50 / 3500 | |
| D516:517 | Y_SOFT_MAX | 0.1 mm | 3750 | ≤ 3700 + حاشیه |
| **D518:519** | **X_SCALE** | پالس در ۱۰۰۰ mm | **100000** | گیربکس ۱:۳ و پولی ۲۴T با 4000 p/rev |
| D520:521 | Y_SCALE | پالس در ۱۰۰۰ mm | 33333 | پولی ۲۴T مستقیم |
| D522 / D523 | X auto / manual | mm/s | 800 / 100 | 50 تا 900 / 5 تا 200 |
| D524 / D525 | X home / creep | mm/s | 60 / 8 | |
| D526 | X_ACC | ms | 300 | 100 تا 1000 |
| D527 / D528 / D529 | Y out / return / jog | mm/s | 400 / 400 / 80 | 50 تا 600 |
| D530 / D531 | Y home / creep | mm/s | 60 / 8 | |
| D532 | Y_ACC | ms | 300 | 100 تا 1000 |
| **D540 / D541** | **DWELL1 / DWELL2** | 10 ms | **50 / 50** | 20 تا 100 (۰.۲ تا ۱.۰ ثانیه) |
| D542 | FLASH_OFF | 10 ms | 0 | |
| D543 / D544 | Z down / up timeout | 10 ms | 150 | |
| D545 | Z_SETTLE | 10 ms | 10 | |
| D546 | CONTINUOUS_PAUSE | 10 ms | 50 | |
| D547 | HOME_TIMEOUT | 100 ms | 300 | |
| D548:549 | POS_TOLERANCE | 0.1 mm | 5 | |
| **D550:551** | **EARLY_Z_LEAD** | 0.1 mm | 300 | 0 تا 1000. فاصله‌ای که Z قبل از رسیدن X پایین آمدن را شروع می‌کند |
| **D552** | **PRE_PICK_MAX_WAIT** | 10 ms | 300 | 50 تا 1000 |
| **D554** | **PRINT_MODE** | – | 0 | 0 = ۱ پدال : ۱ چاپ، 1 = ۱ پدال : N چاپ، 2 = پیوسته |
| **D555** | **MULTI_HIT_N** | عدد | 2 | 1 تا 9 |
| D556 | BURST_COUNT (کاری) | عدد | – | چاپ‌های انجام‌شده در همین پدال |
| D560:561 / D562:563 / D564:565 | TOTAL / BATCH / BATCH_TARGET | pcs | | |
| **D600–D630** | کارگر، شیفت و زمان | – | | جزئیات در [بخش ۱۰](10_operators_shifts_erp.md) |
| **D640–D673** | مناطق ممنوع X، Y و فرود، و فاصله‌ی ایمنی | 0.1 mm | 0 (خاموش) | [بخش ۱۲](12_zones_error_handling.md) |
| D680 / D681 / D682 / D683 / D684 | دلیل‌ها / جعبه‌سیاه (خانه، تعداد) / کد و گام خطای PLC | | | |
| **D603 / D604 / D605** | شروع شیفت ۱ / ۲ / ۳ | hhmm | 600 / 1400 / 2200 | |
| **D3000–D3739** | فهرست کارگران، ضرب هر کارگر، بلوک زنده ERP، دفتر ۶۴ جلسه | – | | بخش ۱۰ |
| D566:567 | PRINT_INTERVAL | 10 ms | – | زمان بین دو چاپ متوالی |
| D568 | PRINTS_PER_HOUR | pcs/h | – | |

## ۲-۵ تایمرها

| تایمر | پایه | کاربرد |
|---|---|---|
| T0 / T1 | 100 ms | Timeout هومینگ X / Y |
| T2 | 100 ms | نوسان‌گیر هوا |
| T3 | 100 ms | Watchdog ارتباط HMI |
| T6 | 100 ms | Plausibility سنسورهای Z |
| T7 | 100 ms | پالس ریست ENA |
| T8 | 100 ms | Watchdog مراحل (۱۵ ثانیه) |
| T200 / T201 | 10 ms | Dwell1 / Dwell2 |
| T202 | 10 ms | Flash-off |
| T203 / T204 | 10 ms | Timeout فرود / صعود Z |
| T205 | 10 ms | نشست Z Up |
| T206 | 10 ms | مکث سیکل پیوسته |
| **T207** | 10 ms | **حداکثر انتظار پد پر (Pre-pick)** |
| T210 | 10 ms | فاصله‌ی بین دو چاپ |

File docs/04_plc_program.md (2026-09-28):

# ۴. برنامه‌ی PLC: توضیح کد نردبانی و اینترلاک‌ها

کد کامل: [`plc/TampoPrinter_SV2.il`](../plc/TampoPrinter_SV2.il) (فرمت Instruction List برای WPLSoft/ISPSoft).
این بخش شبکه‌های کلیدی را به‌صورت نردبانی نشان می‌دهد و دلیل هر تصمیم را توضیح می‌دهد.

> ⚠️ **شماره‌ی دستگاه‌های ویژه** (D1030، D1336، M1029، M1030، M1078، M1104، M1336، M1337، D1343، D1353) از دفترچه‌ی برنامه‌نویسی سری ES2/EX2/SS2/SA2/SX2/SE/**SV2** برداشته شده‌اند. پیش از راه‌اندازی، آن‌ها را با نسخه‌ی دفترچه‌ای که با **فریمور PLC شما** می‌خواند تطبیق دهید. همین‌طور جهت پیش‌فرض DZRN و بیت‌های معکوس‌کننده‌ی جهت (M1305/M1306) را.

## ۴-۱ دستورهای حرکتی استفاده‌شده

| دستور | فرمت | کاربرد در این برنامه |
|---|---|---|
| `DDRVA S1 S2 D1 D2` | S1 = موقعیت مطلق (پالس، ۳۲ بیت)، S2 = فرکانس (Hz)، D1 = خروجی پالس، D2 = خروجی جهت | **تنها** دستور حرکت X و Y. هم برای سیکل اتومات، هم Jog (مقصد = Soft-Limit) و هم Go-To |
| `DZRN S1 S2 S3 D` | S1 = سرعت هوم، S2 = سرعت Creep، S3 = ورودی DOG، D = خروجی پالس | هومینگ دو مرحله‌ای |
| `DDRVI` | حرکت نسبی | **استفاده نشده**. `DDRVA` امن‌تر است: اگر حرکت قطع شود و دوباره شروع شود، به همان مقصد مطلق می‌رسد و خطای جمع‌شونده ندارد |
| `DZCP` | مقایسه‌ی ناحیه‌ای ۳۲ بیتی | تشخیص «در موقعیت» و «داخل ناحیه‌ی کلیشه» |
| `DMUL` و `DDIV` | ضرب و تقسیم ۳۲ بیتی | تبدیل mm به پالس و mm/s به Hz |

**مقیاس‌بندی:** HMI همه‌چیز را بر حسب میلی‌متر نشان می‌دهد و PLC آن را به پالس تبدیل می‌کند:

```
pulses = pos[0.1mm] × SCALE[p/1000mm] / 10000       (7000 × 33333 = 2.3e8 < 2^31 ✔)
Hz     = spd[mm/s]  × SCALE / 1000
pos    = D1030 × 10000 / SCALE                     (نمایش موقعیت جاری)
```

## ۴-۲ اینترلاک‌های ضدبرخورد (نسخه‌ی ۲)

```
 شبکه N04-2 :  پد بالای ارتفاع امن (M26)
 ──┤X20├──┤/X3├──┤/X17├────────────────────────────( M26 )   X20 ناحیه‌ای است (سنسور القایی + تسمه‌ی آهنی)

 شبکه N04-4 :  مجوز حرکت X
 ──┤M26├──┤/X3├──┤/X17├──┤M20├────────────────────( M40 )

 شبکه N04-5 :  مجوز حرکت Y
 ──┬┤M26 ├┬──┤M20├────────────────────────────────( M42 )
   └┤/M30├┘            (پد بالای ارتفاع امن  یا  بیرون از ناحیه‌ی کلیشه)

 شبکه N04-6 :  پنجره‌های فرود زودهنگام
 ──┤M507├──┤M96├──[D90 ≤ D550]──┤M92├─────────────( M63 )   Pick
 ──┤M507├──┤M97├──[D90 ≤ D550]────────────────────( M64 )   Print

 شبکه N04-7 :  مجوز فرود Z
 ──┬┤M31├┬──┤M33├──┬──┤M24├──┤M20├────────────────( M41 )
   └┤M63├┘         │
 ──┬┤M32├┬──┤X16├──┘
   └┤M64├┘
```

* سنسور مگنتی فقط وقتی پیستون **از جلویش رد می‌شود** روشن است. برای همین «بالا یا پایین بودن» از **جهت شیر** (`Y4`) هنگام عبور تشخیص داده می‌شود.
* `D90` فاصله‌ی باقی‌مانده‌ی X تا مقصد است: `DSUB D200 D30` و بعد `DABS`. دستور `DABS` را در دفترچه‌ی SV2 تأیید کنید.

| خطر برخورد | لایه‌ی ۱ (سکانس) | لایه‌ی ۲ (Motion Block) | لایه‌ی ۳ (نظارت) |
|---|---|---|---|
| حرکت X وقتی پد پایین است | مرحله‌ها فقط بعد از `M26` جلو می‌روند | `DDRVA` X در سری با `M40` | **A10**: X در حرکت و پد زیر ارتفاع امن ⇒ توقف فوری |
| فرود روی قطعه حین حرکت X | پنجره‌ی `D550` | – | **A17**: سنسور Down و X در حرکت ⇒ توقف فوری |
| برخورد کاپ با پد روی کلیشه | ترتیب مراحل | `DDRVA` Y در سری با `M42` | **A10** برای Y |
| فرود پد روی کاپ | S20 فقط بعد از `M92` و `M33` | `Y4` در سری با `M41` که شامل `M33` است | A07 |
| فرود روی دست اپراتور | – | `M41` شاخه‌ی Print شامل `X16` | رله‌ی ایمنی تغذیه‌ی `Y4` را قطع می‌کند |
| سنسور Z معیوب | – | `M25` شامل `/X3` و `/X17` | **A09**: Up با Down، یا Safe با Down |

## ۴-۳ بلوک اجرای حرکت (N10)

```
 ──┬┤M45├┬──────────────────────────────────────────( M50 )
   └┤M46├┘
 ──┤M50├──┤M40├──┤/M54├──┤/M29├──[ DDRVA D10 D12 Y0 Y1 ]
 ──┤M54├──┤M40├──┤/M50├──┤/M29├──[ DZRN  D18 D20 X0 Y0 ]
 ──┤/M50├─┤/M54├─┤/M1336├───────────────────────────( M58 )   کانال آزاد
 ──┤M1029├─┬─┤M54├──[RST M54][SET M57]                        پایان هوم
           ├─┤M50├──[RST M45]                                 پایان حرکت
           └────────[RST M1029]
```

**چرا این بلوک باید در انتهای برنامه باشد؟** دستور پالس دلتا برای اجرای دوباره باید دست‌کم **یک اسکن** کنتاکتش OFF دیده شود. ترتیب «اول سکانس‌ها، بعد Motion Block» و شرط `M58` در هر فرمان تضمین می‌کنند که:

```
اسکن n  : حرکت تمام شد → RST M45 → M58 = 0
اسکن n+1: DDRVA کنتاکت OFF را می‌بیند → M58 = 1
اسکن n+2: سکانس مقصد جدید را می‌نویسد و SET M45 → DDRVA دوباره اجرا می‌شود ✔
```

نوشتن مقصد (`D200`) فقط در **لحظه‌ی فرمان** و فقط وقتی کانال آزاد است انجام می‌شود. پس مقصد در طول حرکت ثابت می‌ماند.

## ۴-۴ نمونه‌ی یک مرحله‌ی سکانس (الگوی تکراری)

```
 // S80 : X → Print
 ──[= D0 K80]──┤/M32├──┤/M45├──┤M58├──┤M40├──[DMOV D502 D200][MOV D522 D202][SET M45]
 ──[= D0 K80]──┤M32├──────────────────────────[MOV K90 D0]
```

هر مرحله‌ی حرکتی سه شرط دارد:

1. **در مقصد نیستم** (`/M32`). اگر محور از قبل در مقصد باشد، فرمان حرکت صادر نمی‌شود.
2. **فرمانی در جریان نیست** (`/M45`).
3. **کانال آزاد است و مجوز حرکت هست** (`M58` و `M40`).

## ۴-۵ Z و شیر دوبوبین

```
 ──┬┤M60├┬──┤M41├──────────────────────────────────( Y4 )   SOL DOWN  (+24V از رله‌ی ایمنی)
   └┤M61├┘
 ──┤/Y4├───────────────────────────────────────────( Y5 )   SOL UP    (+24V معمولی)
```

* دو بوبین هیچ‌وقت هم‌زمان روشن نمی‌شوند. بوبین‌ها **دائم** برق دارند (نه پالسی)، پس پس از قطع و وصل برق، وضعیت شیر با وضعیت PLC هماهنگ می‌شود.
* در E-Stop، رله‌ی ایمنی تغذیه‌ی Y4 را **سخت‌افزاری** قطع می‌کند. PLC هم M60 و M61 را Reset می‌کند و Y5 روشن می‌شود، پس پد بالا می‌رود.
* **Dwell از لبه‌ی تأیید سنسور** Down شمرده می‌شود (مرحله‌های S60 و S100)، نه از فرمان شیر.

## ۴-۶ توقف‌ها

| نوع | ماشه | مکانیزم | هوم حفظ می‌شود؟ |
|---|---|---|---|
| Stop پایان سیکل | X13 (NC)، M101، تغییر Mode، پایان بچ | `M91`. سکانس در S10 به Idle می‌رود | ✔ |
| Stop کنترل‌شده (کلاس B) | آلارم‌های فرایندی | Reset شدن درخواست‌ها، پس کنتاکت DDRVA قطع و محور با شیب Decel ترمز می‌کند | ✔ |
| Stop فوری (کلاس A و A′) | `M29` | `SET M1078` و `SET M1104` (قطع فوری پالس) و Reset درخواست‌ها | کلاس A: ✘ |
| E-Stop سخت‌افزاری | رله‌ی ایمنی | قطع تغذیه‌ی Y4، ENA درایورها و (با تأخیر) 48V | ✘ |

> توجه: `M1078` یک «Pause» است. اگر وقتی کنتاکت دستور هنوز ON است Reset شود، حرکت **ادامه پیدا می‌کند**. به همین دلیل در کد، `M1078` فقط وقتی Reset می‌شود که همه‌ی درخواست‌ها (`M50`، `M52`، `M54`، `M55`) خاموش باشند.

## ۴-۷ چک‌لیست راه‌اندازی (Commissioning)

1. **بدون تسمه:** جهت چرخش را با Jog چک کنید. «+» باید از سمت هوم دور شود. اگر برعکس است، جهت را در CL57 (DIP یا ProTuner) عوض کنید، نه در سیم‌بندی.
2. جهت DZRN را چک کنید. باید **به سمت** سنسور هوم برود. اگر نمی‌رود، M1305/M1306 یا تنظیم جهت درایور را طبق دفترچه اصلاح کنید.
3. درایورها را روی **4000 pulse/rev** بگذارید. مقیاس X با گیربکس ۱:۳: `D518 = 100000` (۱۰۰ پالس در mm). مقیاس Y: `D520 = 33333`. برای کالیبره کردن، ۶۰۰ mm حرکت دهید، با خط‌کش اندازه بگیرید و مقیاس را اصلاح کنید: `SCALE_new = SCALE × 600 / measured`.
4. بدون فشار هوا: `X15 = 0`، پس A06 باید فعال شود.
5. سنسورهای Z: پد بالا باید `X2 = 1` بدهد. پد روی کلیشه با **پد فشرده** باید `X3 = 1` بدهد. سنسور را در نقطه‌ای بگذارید که پد حدود ۵ تا ۱۵ mm فشرده شده باشد. سنسور **Safe (X20)** را طوری تنظیم کنید که درست وقتی پد از کاپ، لبه‌ی کلیشه و دیسک **دست‌کم ۱۰ mm** بالاتر است خاموش شود. هر سه سنسور القایی روی شیار براکت `P17` تنظیم می‌شوند؛ نقطه‌های قطع در بخش ۸ `cad/out/check_report.md` آمده است.
6. موقعیت‌های Pick و Print و مرزهای ناحیه‌ی کلیشه (`D508` و `D510`) را با Jog پیدا و در HMI ثبت کنید. **ناحیه را دست‌کم نصف قطر پد بزرگ‌تر از کاپ بگیرید.**
7. سیکل خشک: `M503 = 1` (Dry-Run). یک سیکل کامل بدون فرود Z اجرا کنید.
8. تست اینترلاک‌ها: در حالت دستی X را حرکت دهید و Z را با دست (شیر دستی) پایین بیاورید. باید A10 صادر شود و محور فوراً بایستد.
8-1. تنظیم هم‌پوشانی: اول با `M507 = 0` و `M506 = 0` سیکل را پایدار کنید. بعد `M507 = 1` و `D550` را از ۵ mm به بالا ببرید (بخش ۳-۴). در آخر `M506 = 1` (برداشت زودتر).
9. تست E-Stop در هر مرحله‌ی سکانس: پد باید بالا برود و محورها بایستند.
10. زمان سیکل را روی HMI ببینید. شتاب و سرعت را کم‌کم بالا ببرید تا CL57 آلارم Position Error ندهد، بعد ۲۰٪ عقب بکشید.

## ۴-۸ فایل‌های برنامه و تست شبیه‌سازی

| فایل | کاربرد |
|---|---|
| `plc/TampoPrinter_SV2.il` | برنامه با توضیحات (برای خواندن) |
| `plc/TampoPrinter_SV2_clean.txt` | همان برنامه **بدون توضیحات**، برای Paste در حالت Instruction نرم‌افزار **WPLSoft** (یا ISPSoft با زبان IL) |
| `plc/device_comments.csv` | توضیح آدرس‌ها برای جدول Device Comment |
| `tools/plc_sim.py` | **شبیه‌ساز:** برنامه را اسکن‌به‌اسکن اجرا می‌کند، با مدل محورها، جک Z و سنسورها |

**وارد کردن در WPLSoft:** New Project با مدل **SV2**، بعد View → Instruction Mode، و محتوای فایل clean را Paste کنید. سپس Compile. اگر نسخه‌ی نرم‌افزار Paste گروهی را قبول نکرد، دستورها را با همان متن در حالت Instruction تایپ کنید.

**نتیجه‌ی شبیه‌سازی** (`python3 tools/plc_sim.py`):

| سناریو | نتیجه |
|---|---|
| سیکل ساده، بدون گزینه‌ها | ✅ هومینگ، ۵ چاپ، بدون آلارم و بدون برخورد |
| جوهرزنی موازی | ✅ |
| جوهرزنی موازی + فرود زودهنگام ۵ mm | ✅ |
| همه‌ی گزینه‌ها + برداشت زودتر | ✅ |
| فرود زودهنگام ۳۰ mm (عمداً زیاد) | ✅ A10 و توقف ایمن، بدون برخورد |
| افتادن پد حین حرکت X (خرابی شیر یا هوا) | ✅ A10 و توقف فوری X |

> شبیه‌ساز منطق برنامه را تأیید می‌کند، نه زمان‌بندی دقیق فریمور دلتا. با شبیه‌ساز یک باگ واقعی پیدا و رفع شد: A10 قبلاً فعال نمی‌شد، چون قطع مجوز حرکت، پالس را زودتر از بررسی آلارم قطع می‌کرد.

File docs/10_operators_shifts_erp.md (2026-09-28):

# ۱۰. کارگران، شیفت‌ها و ارسال آمار به ERP

## ۱۰-۱ کارگر چه می‌کند؟

1. روی نمایشگر، دکمه‌ی **کارگر** در نوار بالا را لمس می‌کند. صفحه‌کلید بزرگ باز می‌شود.
2. **چهار رقم آخر کد ملی** خودش را می‌زند و «ورود» را لمس می‌کند.
3. اگر کد در فهرست کارگران باشد، وارد می‌شود. از این لحظه هر ضربه‌ای که دستگاه می‌زند به حساب او و شیفت فعلی ثبت می‌شود. اگر کد در فهرست نباشد، پیام «کد نامعتبر» ۳ ثانیه نشان داده می‌شود.
4. روی صفحه‌ی اصلی می‌بیند: **«ضرب‌های شما در این شیفت»**.
5. آخر کار «خروج» را می‌زند. اگر کارگر بعدی بدون خروج قبلی وارد شود، جلسه‌ی قبلی خودکار بسته می‌شود.

> با گزینه‌ی **«ورود کارگر برای شروع الزامی است»** (`M508`، پیش‌فرض روشن)، دستگاه بدون ورود کارگر شروع به کار نمی‌کند.

## ۱۰-۲ شیفت‌ها

| شیفت | شروع (پیش‌فرض) | رجیستر |
|---|---|---|
| ۱ | 06:00 | `D603` = 600 |
| ۲ | 14:00 | `D604` = 1400 |
| ۳ | 22:00 تا 06:00 روز بعد | `D605` = 2200 |

* شیفت از **ساعت داخلی PLC** تعیین می‌شود. ساعت PLC را درست تنظیم کنید. دروازه‌ی ERP یا HMI می‌تواند آن را هر روز با ساعت شبکه هماهنگ کند.
* **در لحظه‌ی تغییر شیفت:** جلسه‌ی کارگر فعلی بسته و ثبت می‌شود، شمارنده‌های شیفت صفر می‌شوند، و اگر همان کارگر ادامه دهد، یک جلسه‌ی جدید برای او در شیفت جدید باز می‌شود. تولید متوقف نمی‌شود.

## ۱۰-۳ داده‌ها در PLC

| آدرس | محتوا |
|---|---|
| `D3000–D3039` | **فهرست ۴۰ کارگر:** کد ۴ رقمی (از HMI صفحه‌ی ۹ یا از ERP نوشته می‌شود) |
| `D3040–D3079` | ضرب‌های هر کارگر در شیفت فعلی (هم‌اندیس با فهرست) |
| `D600` / `M130` / `M131` | کد واردشده / فرمان ورود / فرمان خروج (از HMI) |
| `D601` / `M132` / `M133` | کارگر فعلی / واردشده / کد نامعتبر |
| `D602` | شیفت فعلی (۱ تا ۳) |
| `D606:607` / `D616` | ضرب‌های جلسه‌ی فعلی / ضرب‌های کارگر فعلی در این شیفت |
| `D611:612` | ضرب‌های دستگاه در این شیفت |
| `D3080–D3095` | **بلوک زنده برای ERP** (جدول ۱۰-۵) |
| `D3100–D3739` | **دفتر جلسه‌های کاری:** ۶۴ رکورد × ۱۰ Word، حلقوی |
| `D3097` / `D627` | شماره‌ی ترتیب آخرین رکورد / خانه‌ی بعدی |

**هر رکورد جلسه (۱۰ Word):**

| Word | محتوا |
|---|---|
| 0 | کد کارگر |
| 1 | شیفت |
| 2 / 3 | تاریخ شروع MMDD / سال (دو رقم) |
| 4 / 5 | ساعت شروع / پایان (hhmm) |
| 6–7 | تعداد ضرب (۳۲ بیتی) |
| 8 | شماره‌ی ترتیب (برای اینکه ERP هر رکورد را دقیقاً یک بار بخواند) |

**۶۴ رکورد** یعنی اگر شبکه یا ERP چند روز قطع باشد، (با حدود ۳ تا ۶ جلسه در روز) داده‌ای از دست نمی‌رود.

## ۱۰-۴ اتصال شبکه

```
[DVP-28SV2] ─ [DVPEN01-SL] ── Ethernet ── سوئیچ کارخانه ── [رایانه‌ی دروازه] ── HTTP(S) ── [ERP]
               Modbus TCP :502                                tools/erp_gateway.py
```

* **سخت‌افزار:** نه PLC (DVP-28SV2) و نه نمایشگر (DOP-107BV) پورت شبکه ندارند. یک ماژول اترنت سمت چپ PLC لازم است: **Delta DVPEN01-SL** (Modbus TCP). نام و سازگاری آن را با فروشنده‌ی دلتا تأیید کنید. گزینه‌ی دیگر: نمایشگر **DOP-107EV** که اترنت دارد.
* **دروازه:** برنامه‌ی `tools/erp_gateway.py` روی هر رایانه‌ی ویندوز یا لینوکس در شبکه (یا یک مینی‌PC کوچک):
  * هر ۵ ثانیه وضعیت زنده را می‌خواند و به ERP می‌فرستد.
  * رکوردهای جدید جلسه را **یک بار** می‌خواند و در یک فایل پشتیبان محلی می‌نویسد. بعد به ERP می‌فرستد. اگر ERP در دسترس نباشد، بعداً دوباره تلاش می‌کند.
  * می‌تواند فهرست کارگران را از ERP به PLC بفرستد: `python erp_gateway.py --registry 1234,5678,...`
* **آدرس‌دهی Modbus دلتا:** `D n` = Holding Register `0x1000 + n`. مثلاً `D3080` = 7176.

## ۱۰-۵ بلوک زنده (یک بار خواندن ۱۶ رجیستر از D3080)

| رجیستر | محتوا |
|---|---|
| D3080 | وضعیت دستگاه (۰ هوم نشده، ۱ هومینگ، ۲ آماده، ۳ اتومات، ۴ در حال توقف، ۵ آلارم) |
| D3081 | کد کارگر فعلی |
| D3082 | شیفت |
| D3083:84 | ضرب‌های جلسه |
| D3085:86 | ضرب‌های دستگاه در این شیفت |
| D3087:88 | شمارنده‌ی کل |
| D3089 | چاپ در ساعت |
| D3090 / D3091 | کلمه‌های آلارم |
| D3092 | حالت چاپ |
| D3093 / D3094 | شماره‌ی آخرین رکورد / خانه‌ی بعدی |
| D3095 | ضرب‌های کارگر فعلی در این شیفت |

## ۱۰-۶ داده‌ای که به ERP می‌رسد (JSON)

```json
{"type":"session","machine":"TAMPO-01","operator":1234,"shift":1,
 "date":"2026-09-28","start":"06:30","end":"10:30","prints":312,"seq":117}

{"type":"status","machine":"TAMPO-01","state":"auto","operator":1234,"shift":1,
 "session_prints":45,"shift_prints":1240,"total_prints":12540,"prints_per_hour":818,
 "alarms":[],"print_mode":"1_pedal_1_print","operator_shift_prints":186}
```

ERP با جمع کردن رکوردهای `session` بر اساس `operator` و `shift` و `date`، کارکرد هر کارگر در هر شیفت را دارد. تیم ERP باید یک آدرس (Endpoint) برای دریافت این JSON آماده کند. اگر ERP شما به‌جای آن مستقیم به پایگاه داده (SQL) وصل می‌شود، فقط تابع `post_erp` در دروازه عوض می‌شود.

## ۱۰-۷ تست‌ها

| تست | نتیجه |
|---|---|
| شبیه‌ساز PLC: شروع بدون ورود رد می‌شود، کد نامعتبر رد می‌شود، ورود ۱۲۳۴، ۳ ضرب، ورود ۵۶۷۸ و ثبت رکورد ۱۲۳۴، ۲ ضرب، تغییر شیفت و ثبت رکورد ۵۶۷۸، خروج | ✅ هر ۱۱ بررسی قبول (`python3 tools/plc_sim.py`) |
| دروازه: رمزگشایی بلوک زنده، رکوردها با عبور شماره از ۶۵۵۳۵، فایل پشتیبان | آزمون واحد |
| دروازه در برابر یک PLC شبیه‌سازی‌شده روی Modbus TCP واقعی | ✅ دو رکورد، هر کدام دقیقاً یک بار |

> ⚠️ شماره‌ی رجیسترهای ساعت PLC (`D1314` دقیقه، `D1315` ساعت، `D1316` روز، `D1317` ماه، `D1319` سال) و آدرس‌دهی Modbus ماژول اترنت را با دفترچه‌ی دلتا تطبیق دهید.

> **حریم خصوصی:** فقط ۴ رقم آخر کد ملی ذخیره می‌شود و کد کامل هیچ‌جا نگه داشته نمی‌شود. اگر دو کارگر ۴ رقم آخر یکسان داشته باشند، به یکی از آن‌ها یک کد جایگزین بدهید. PLC کد تکراری را رد نمی‌کند و ضرب‌ها به حساب آخرین ردیف با آن کد می‌رود.

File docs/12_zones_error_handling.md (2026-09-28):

# ۱۲. مناطق ممنوع، مدیریت خطا و بازیابی نرم‌افزاری

## ۱۲-۱ مناطق ممنوع (صفحه‌ی ۱۱ HMI، سطح مهندس)

| نوع | تعداد | رجیستر | چه می‌کند |
|---|:-:|---|---|
| **X: محور وارد نمی‌شود** | ۴ | `D640 + 4k` (شروع) و `D642 + 4k` (پایان)، DW، 0.1 mm | حرکتی که مقصد یا **مسیرش** از منطقه بگذرد اجرا نمی‌شود (**A18**). Jog پیش از لبه می‌ایستد |
| **Y: کاپ وارد نمی‌شود** | ۲ | `D656 + 4k` و `D658 + 4k` | همان رفتار برای Y |
| **فرود پد ممنوع (روی X)** | ۲ | `D664 + 4k` و `D666 + 4k` | اگر X در این محدوده باشد، پد پایین نمی‌آید. در اتومات، اگر مرحله‌ی فرود به این منطقه برسد، بلافاصله **A18** |
| فاصله‌ی ایمنی Jog | ۱ | `D672` (DW) | Jog این مقدار پیش از لبه می‌ایستد (پیش‌فرض ۲ mm) |

**قاعده‌ها:**
* منطقه وقتی **فعال** است که «پایان» بزرگ‌تر از «شروع» باشد. برای خاموش کردن، هر دو را ۰ بگذارید.
* مناطق فقط **بعد از هومینگ** فعال‌اند، چون قبل از آن موقعیت معلوم نیست.
* اگر محور به هر دلیلی **داخل** منطقه باشد (مثلاً منطقه دور محل فعلی تعریف شده یا محور با دست هل داده شده)، **A19** با توقف فوری می‌آید. بعد از ریست، Jog برای **بیرون آمدن** مجاز است.
* **سه لایه‌ی حفاظت:**
  1. Jog را پیش از لبه محدود می‌کند (P2، P3، P6، P7).
  2. پیش از هر حرکت، کل مسیر بررسی می‌شود (P4، P5).
  3. حین حرکت، ورود به منطقه پایش می‌شود (A19).

## ۱۲-۲ مدیریت خطا

| سازوکار | آدرس | رفتار |
|---|---|---|
| **خطای اجرای برنامه‌ی PLC** | `M1067` → **A20**، کد خطا `D683`، گام برنامه `D684` | مثلاً آدرس اندیس‌دار خارج از محدوده. به‌جای رفتار نامعلوم، سکانس‌ها لغو و پد بالا می‌رود. محل دقیق خطا روی صفحه‌ی عیب‌یابی نشان داده می‌شود |
| **تعمیر رجیسترهای مرحله** | `M170` → **A21** | اگر مرحله‌ی یکی از سکانس‌ها (`D0` تا `D4`) مقدار نامعتبر بگیرد (خرابی حافظه یا نوشتن اشتباه از شبکه یا HMI)، همه به صفر برمی‌گردند و دستگاه در حالت امن می‌ایستد |
| **Watchdog هر مرحله** | **A16** | هیچ مرحله‌ای بیش از ۱۵ ثانیه گیر نمی‌کند |
| **Watchdog ارتباط HMI** | **A14** | با قطع ارتباط، همه‌ی فرمان‌های نگه‌داشته‌ی HMI پاک می‌شوند |
| **Watchdog اسکن PLC** | داخلی دلتا (`D1000`) | اگر اسکن گیر کند، خود PLC خروجی‌ها را قطع می‌کند |
| **جعبه‌سیاه** | `D3750–D3877`، تعداد `D682` | ۱۶ خطای آخر: کد اولین آلارم، مرحله‌ی هر سکانس، ساعت، تاریخ، موقعیت X، و دلیل‌های `D680` در همان لحظه |
| **چرا شروع نمی‌کند؟** | `D680` (۱۳ بیت) | دلیل‌ها به زبان ساده روی صفحه‌ی عیب‌یابی نشان داده می‌شوند، با کاری که باید کرد |
| **محدود کردن پارامترها** | N01 | مقادیر بیرون از بازه به نزدیک‌ترین مقدار مجاز برمی‌گردند (محل برداشت و چاپ، مکث‌ها و سرعت‌ها) |

## ۱۲-۳ بازیابی نرم‌افزاری، بدون خاموش کردن دستگاه

| فرمان | سطح | چه می‌کند |
|---|---|---|
| **ریست** (`M102`) | اپراتور | پاک کردن آلارم‌هایی که علتشان رفع شده |
| **بازنشانی نرم‌افزاری** (`M141`) | سرپرست | توقف همه‌ی حرکت‌ها، لغو همه‌ی سکانس‌ها، پد بالا، پاک کردن آلارم‌ها و خطای PLC، پالس ENA درایورها. **هومینگ حفظ می‌شود** مگر اینکه موقعیت از دست رفته باشد. بعد از آن، دکمه‌ی شروع دوباره کار می‌کند |
| **تنظیمات کارخانه** (`M140`) | مهندس | همه‌ی پارامترها و مناطق به مقدار پیش‌فرض برمی‌گردند (زیرروال P9). فقط وقتی دستگاه متوقف است |

**«دیباگ خودکار» به چه معناست؟** برنامه نمی‌تواند باگ خودش را بنویسد و درست کند. کاری که می‌کند این است:
1. **تشخیص می‌دهد:** سنسورها، مرحله‌ها، زمان‌ها و خطاهای خود PLC را پایش می‌کند.
2. **جلوی آسیب را می‌گیرد:** در هر حالت ناشناخته به حالت امن می‌رود (توقف و پد بالا). هرگز در حالت نیمه‌کاره حرکت نمی‌کند.
3. **خودش را ترمیم می‌کند:** رجیسترهای خراب صفر می‌شوند و بازنشانی نرم‌افزاری بدون خاموش کردن کار می‌کند.
4. **ثبت می‌کند:** جعبه‌سیاه و صفحه‌ی عیب‌یابی نشان می‌دهند خطا **کجا و در چه مرحله‌ای** رخ داد، تا باگ واقعی سریع پیدا و اصلاح شود.

## ۱۲-۴ تست

همه‌ی موارد بالا در [گزارش تست](11_test_report.md) با تزریق خطا آزموده شده‌اند:
* **مناطق:** سناریوهای S29 تا S33.
* **خطای PLC:** S34.
* **رجیستر خراب:** S35.
* **بازنشانی نرم‌افزاری:** S36.
* **تنظیمات کارخانه:** S37.
* **جعبه‌سیاه:** S38.
* **دلیل‌ها:** S39.
* **فازینگ تصادفی:** S42 تا S44. هزاران فرمان و خطای تصادفی، بدون حتی یک برخورد، و بازیابی کامل در پایان.

> ⚠️ شماره‌های `M1067`، `D1067` و `D1068` (خطای اجرای برنامه) را با دفترچه‌ی SV2 تطبیق دهید.

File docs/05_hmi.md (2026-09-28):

# ۵. ساختار HMI (Delta DOP-107BV)

> **نمونه‌ی تعاملی صفحات:** [`hmi/hmi_mockup.html`](../hmi/hmi_mockup.html). هر شیء با آدرس PLC و نوع شیء DOPSoft مشخص شده است.

## ۵-۱ ارتباط

| مورد | مقدار |
|---|---|
| پورت HMI | COM2 (RS-485) |
| پورت PLC | COM2 روی SV2 (RS-485، ترمینال +/−) |
| درایور DOPSoft | **Delta DVP PLC** (Modbus RTU) |
| تنظیمات | 115200، 8، E، 1 (در PLC با `D1120` و `M1120` ست شود)، Station = 1 |
| کابل | زوج به‌هم‌تابیده‌ی شیلددار (مثل Belden 3105A). شیلد فقط از **سمت PLC** به PE وصل شود. در انتهای خط مقاومت ترمیناتور ۱۲۰ اهم |
| **Heartbeat** | Cycle Macro در HMI با دوره‌ی ۵۰۰ ms: `D60 = D60 + 1`. PLC اگر ۲ ثانیه تغییری نبیند آلارم A14 می‌دهد و همه‌ی بیت‌های `M100` تا `M119` را پاک می‌کند |

## ۵-۲ نقشه‌ی صفحات

```
                    ┌──────────────┐
                    │ 0  Splash    │ (بعد از ۳ ثانیه)
                    └──────┬───────┘
                           ▼
 ┌───────────────── 1  MAIN / AUTO (صفحه‌ی اصلی) ──────────────────┐
 │  ناوبری پایین: [Auto] [Manual] [Param] [Recipe] [Count] [Alarm] [I/O] [Setup] │
 └────────────────────────────────────────────────────────────────┘
    │          │           │          │          │         │        │
    ▼          ▼           ▼          ▼          ▼         ▼        ▼
 2 Manual  3 Motion     4 Process  5 Recipe  6 Counter  7 Alarm  8 I/O Diag
           Param        Param                           7b History
                                                                    9 Setup (Engineer)
```

### سطح دسترسی

| سطح | کاربر | صفحه‌ها |
|---|---|---|
| 0 | اپراتور | 1، 6 (فقط نمایش)، 7، 8 |
| 1 | سرپرست / Setter | + 2، 4، 5، ریست شمارنده‌ی بچ |
| 2 | مهندس | + 3، 9، ریست شمارنده‌ی کل، مقیاس، Soft-Limit، زون |

## ۵-۳ جزئیات صفحات

### صفحه‌ی ۱: اصلی (صفحه‌ی کارگر)

طراحی برای کار سریع با دست، حتی با دستکش: دکمه‌های اصلی دست‌کم **۱۶۰×۱۰۰ پیکسل**، اعداد بزرگ، و **بدون گزینه‌های فنی**.

| بخش | اشیاء | آدرس |
|---|---|---|
| نوار وضعیت بزرگ | پیام وضعیت و مرحله، و «چاپ ۲ از ۳» | D9، D0، D556 / D555 |
| **سه کاشی حالت** | ۱ پدال = ۱ چاپ · ۱ پدال = N چاپ (با دکمه‌های بزرگ − و +) · پیوسته | Set Value روی **D554** = 0 / 1 / 2 و N روی **D555** (۱ تا ۹). غیرفعال وقتی M90 = 1 |
| **فاصله‌ی چاپ** | عدد بزرگ میلی‌متر (لمس = کیبورد)، دکمه‌های **−10، −1، +1، +10 mm**، و نقشه‌ی مسیر (محل کلیشه، محل چاپ، جای کالسکه) | **D502** (DW، 0.1 mm؛ دکمه‌ها Add ±10 و ±100). PLC مقدار را بین 0 و D506 محدود می‌کند و در حرکت بعدی اعمال می‌شود |
| شروع و توقف | دو دکمه‌ی خیلی بزرگ سبز و قرمز | M100، M101 |
| شمارنده‌ها | بچ و نوار پیشرفت، کل، چاپ در ساعت | D562 / D564، D560، D568 |
| ریست و هومینگ | دکمه‌های متوسط | M102، M103 |

**فونت:** IRANSans با وزن‌های مختلف (Light برای توضیح، Medium برای برچسب، Bold و Black برای اعداد و دکمه‌ها). DOPSoft از فونت‌های نصب‌شده روی ویندوز استفاده می‌کند، پس نسخه‌ی دارای مجوز IRANSans را روی رایانه‌ی طراح نصب کنید. برای اعداد، نسخه‌ی **FaNum** اعداد فارسی نشان می‌دهد.

گزینه‌های فنی (جوهرزنی موازی، برداشت زودتر، فرود زودهنگام، اجرای خشک و بچ) به **صفحه‌ی ۴ (سرپرست)** منتقل شدند.

### صفحه‌ی ۲: Manual (فقط وقتی `M38 = 1`؛ در غیر این صورت دکمه‌ها غیرفعال)

| گروه | کنترل‌ها | نوع دکمه |
|---|---|---|
| X | `◄ Jog−` (M105)، `Jog+ ►` (M104)، `→Pick` (M110)، `→Print` (M111) | Jog: **Momentary**. Go-To: Set ON |
| Y | `◄ Jog−` (M107)، `Jog+ ►` (M106)، `→Park` (M112)، `→End` (M113)، `Test Stroke` (M117) | |
| Z | `▼ Down` (M108)، `▲ Up` (M109) | Set ON. نشانگر مجوز `M41` را نشان می‌دهد |
| Teach | `Teach Pick` (کپی `D30` به `D500`)، `Teach Print` (کپی `D30` به `D502`)، `Teach Y End` | Macro با تأیید دوباره |
| نمایش | موقعیت X و Y، سنسورها، مجوزهای M40، M41، M42 | چراغ |

### صفحه‌ی ۳: Motion Param (سطح ۲)

| پارامتر | آدرس | واحد | Min | Max | فرمت |
|---|---|---|---|---|---|
| X Pick | D500 (DW) | mm | 0 | 620.0 | 4.1 |
| X Print | D502 (DW) | mm | 0 | 620.0 | 4.1 |
| X Park (بعد از هومینگ) | D504 (DW) | mm | 0 | 620.0 | 4.1 |
| X Soft Max | D506 (DW) | mm | 0 | 620.0 | 4.1 |
| Cliché Zone Min / Max | D508 / D510 (DW) | mm | 0 | 620.0 | 4.1 |
| Y Park / End | D512 / D514 (DW) | mm | 0 | 375.0 | 4.1 |
| Y Soft Max | D516 (DW) | mm | 0 | 375.0 | 4.1 |
| X speed auto / manual | D522 / D523 | mm/s | 50 / 5 | 900 / 200 | 3.0 |
| X accel | D526 | ms | 100 | 1000 | |
| Y speed out / return / jog | D527 / D528 / D529 | mm/s | 50 | 600 | |
| Y accel | D532 | ms | 100 | 1000 | |
| Home / creep X, Y | D524 / D525، D530 / D531 | mm/s | 2 | 150 | |
| Tolerance | D548 (DW) | mm | 0.1 | 2.0 | 1.1 |

### صفحه‌ی ۴: Process Param (سطح ۱)

| پارامتر | آدرس | نمایش | Min تا Max |
|---|---|---|---|
| **Dwell 1 (برداشت)** | D540 | s، 2 رقم اعشار | **0.20 تا 1.00** (پیش‌فرض 0.50) |
| **Dwell 2 (چاپ)** | D541 | s | **0.20 تا 1.00** (پیش‌فرض 0.50) |
| **فاصله‌ی فرود زودهنگام** | D550 (DW) | mm، 1 رقم اعشار | 0 تا 100.0 (سطح ۲) |
| **حداکثر انتظار پد پر** | D552 | s | 0.50 تا 10.00 |
| Flash-off | D542 | s | 0.00 تا 2.00 |
| Continuous pause | D546 | s | 0.00 تا 10.00 |
| Z timeout down / up | D543 / D544 | s | 0.50 تا 5.00 |
| Z settle | D545 | s | 0.00 تا 0.50 |
| Batch target | D564 (DW) | pcs | 0 تا 999999 |
| گزینه‌ها | M500 تا M504، **M506 (برداشت زودتر)**، **M507 (فرود زودهنگام، سطح ۲)** | Toggle | |

### صفحه‌ی ۵: Recipe

* Recipe یک‌بعدی DOPSoft: **۵۰ دستور کار، هر کدام ۳۲ Word** (بازه‌ی D500 تا D547، بدون مقیاس‌ها). مقیاس‌ها با قفل مهندسی جداگانه ذخیره شوند.
* فیلد «نام محصول» در Recipe (رشته‌ی ۱۶ کاراکتری در حافظه‌ی داخلی HMI).
* دکمه‌های `Load`، `Save`، `Save As`. Load فقط در حالت **دستی و متوقف** مجاز است (شرط `M38`).

### صفحه‌ی ۶: Counters و Statistics

* Total (D560، فقط نمایش)، Batch (D562)، Target (D564)، `Reset Batch` (M116، سطح ۱)، `Reset Total` (M115، سطح ۲ با تأیید).
* نمودار روند زمان سیکل (Trend با نمونه‌برداری از D566 در هر ۱۰ ثانیه).

### صفحه‌ی ۷: Alarm

* **Alarm Setup** در DOPSoft: ۱۶ بیت از `D50` (Bit 0 = A01) و بیت 0 از `D51` (A17).
* پیام هر آلارم با **علت و اقدام اصلاحی** (از جدول بخش ۶-۵).
* تاریخچه‌ی آلارم با زمان وقوع، زمان رفع و شمارش (Alarm History روی حافظه‌ی HMI).

### صفحه‌ی ۸: I/O Diagnostics

* چراغ برای X0 تا X17 و Y0 تا Y13 با نام فارسی.
* مقدار زنده‌ی `D1030` و `D1336` (پالس)، `D0` و `D1` و `D2` و `D3` و `D4` (مرحله‌ها)، `D60` (Heartbeat).

### صفحه‌ی ۹: Setup (مهندسی)

* مقیاس‌ها (D518، D520) و **Wizard کالیبراسیون**: حرکت ۶۰۰ mm، ورود مقدار اندازه‌گیری‌شده، محاسبه‌ی مقیاس جدید با Macro.
* Watchdog (M505)، Timeout هوم (D547)، رمزها، تنظیمات ارتباط.

## ۵-۴ فهرست Tagها

فهرست کامل Tagها برای Import یا ورود دستی در DOPSoft: [`hmi/tag_list.csv`](../hmi/tag_list.csv)

## ۵-۵ نکات DOPSoft

* هر مقدار ۳۲ بیتی را با **Data Type = Double Word (Signed)** تعریف کنید. برای نمایش 0.1 mm، گزینه‌ی **Integer Digits = 4 و Fraction = 1** را بزنید. خود PLC همه‌چیز را در 0.1 mm نگه می‌دارد، پس هیچ ضرب و تقسیمی در HMI لازم نیست.
* زمان‌ها در واحد 10 ms ذخیره شده‌اند و با **Fraction = 2** مستقیم بر حسب ثانیه دیده می‌شوند.
* برای هر ورودی عددی، Min و Max را در HMI تعریف کنید (لایه‌ی اول). PLC هم در شبکه‌ی N01 مقدار را محدود می‌کند (لایه‌ی دوم).
* دکمه‌های Jog: **Momentary**. همه‌ی دکمه‌های دیگر: **Set ON**. PLC پس از یک اسکن آن‌ها را خودش Reset می‌کند.
* پنجره‌ی Pop-up آلارم با شرط `D50 ≠ 0`.

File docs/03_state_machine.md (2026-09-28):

# ۳. ماشین وضعیت (FSM / Step Logic)

## ۳-۱ معماری کلی

برنامه از چند ماشین وضعیت **مستقل** ساخته شده است. هر کدام یک رجیستر مرحله (Step) دارد. «درخواست حرکت» هم از «اجرای حرکت» جداست:

```
            ┌────────────── HMI / پنل ──────────────┐
            │  Mode(M120)  Start  Stop  Home  Jog     │
            └───────┬───────────┬───────────┬────────┘
                    ▼           ▼           ▼
             ┌──────────┐ ┌──────────┐ ┌──────────┐
             │ AUTO  D0 │ │ HOME  D2 │ │ MANUAL   │
             └────┬─────┘ └────┬─────┘ └────┬─────┘
                  │  ┌─────────┴──────┐     │
                  │  │ X-sub D3 Y-sub D4│    │
                  │  └─────────┬──────┘     │
                  │   ┌────────┴─────┐      │
                  └──►│  INK  D1 (Y) │◄─────┘
                      └──────┬───────┘
     درخواست‌ها: M45/M46 (X), M47/M48 (Y), M54/M55 (DZRN), M60/M61 (Z)
                             ▼
   ┌──────────────── MOTION BLOCK (آخر برنامه) ─────────────────┐
   │ اینترلاک:  M40 (X)   M42 (Y)   M41 (Z-Down)   M29 (Stop)     │
   │ یک DDRVA و یک DZRN برای هر کانال  ─► Y0/Y1, Y2/Y3           │
   └─────────────────────────────────────────────────────────────┘
```

**قاعده‌ی طلایی:** برای هر کانال پالس فقط **یک** دستور `DDRVA` و **یک** `DZRN` در کل برنامه وجود دارد. همه‌ی حالت‌ها (اتومات، Jog، Go-To، عقب‌نشینی هوم) فقط مقصد را در `D200` یا `D204` و سرعت را در `D202` یا `D206` می‌نویسند و بیت درخواست را فعال می‌کنند. این کار دو مشکل رایج PLCهای دلتا را حذف می‌کند:

1. تداخل چند دستور پالس روی یک خروجی (فقط اولی اجرا می‌شود و بقیه بی‌صدا نادیده گرفته می‌شوند).
2. اجرا نشدن دوباره‌ی دستور، چون کنتاکت بین دو حرکت حتی یک اسکن هم OFF نشده است. پرچم `M58/M59` («کانال دست‌کم یک اسکن آزاد بوده است») این مشکل را حل می‌کند.

## ۳-۲ حالت‌های کلی ماشین (D9)

```mermaid
stateDiagram-v2
    [*] --> NotHomed : روشن شدن
    NotHomed --> Homing : HMI Home (M103)
    Homing --> Ready : H40 تمام شد
    Ready --> Auto : Start (X12/M100) + Mode=Auto
    Auto --> Stopping : Stop / پایان بچ / تغییر به دستی
    Stopping --> Ready : رسیدن به S10
    Ready --> Manual : Mode=Manual
    Manual --> Ready
    NotHomed --> Alarm
    Homing --> Alarm
    Ready --> Alarm
    Auto --> Alarm : هر آلارم
    Alarm --> NotHomed : Reset (آلارم کلاس A)
    Alarm --> Ready : Reset (آلارم کلاس B)
```

## ۳-۳ سکانس هومینگ (D2 و زیرسکانس‌های D3 و D4)

| مرحله | عمل | شرط عبور | خطا |
|---|---|---|---|
| H10 | M60 و M61 Reset، پاک کردن پرچم‌های هوم، پد بالا | `M25` (Z بالا و تأییدشده) | A08 (Timeout صعود Z) |
| H20 | شروع موازی زیرسکانس‌های X و Y | – | – |
| H30 | انتظار | `D3=0` و `D4=0` و `M24` | A11 / A12 |
| H40 | X ← Park و Y ← Park | `M34` و `M33` | A16 |

**زیرسکانس هر محور (X با D3، Y با D4):**

| مرحله | عمل | توضیح |
|---|---|---|
| 10 | اگر روی سنسور است، موقعیت ← 0 و **عقب‌نشینی ۳۰ mm** با سرعت Creep | DZRN اگر روی DOG شروع شود رفتار نامعین دارد |
| 15 | انتظار پایان عقب‌نشینی | |
| 20 | اگر هنوز روی DOG است: **A11 یا A12 (سنسور گیر کرده)**. وگرنه `DZRN` | سرعت هوم و Creep (دو مرحله‌ای، دقت تکرارپذیری) |
| 25 | پایان DZRN: `D1030 ← 0`، `M22 ← 1` | Timeout کل زیرسکانس با `D547` |

> **ترتیب ایمن:** اول Z بالا، بعد X و Y هم‌زمان. چون پد بالاست، بین کاپ و پد تداخلی نیست. اگر Z بالا نرود، هومینگ شروع نمی‌شود.

## ۳-۴ سیکل اتومات (D0) — نسخه‌ی ۲

```mermaid
flowchart TD
    S5["S5  رفتن به شروع<br/>X→Pick , Y→Park"] --> S10
    S10{"S10  تصمیم"} -->|Stop Req| IDLE([S0 Idle])
    S10 -->|"Pre-pick و پد خالی"| S20
    S10 -->|"Pre-pick و پد پر و پدال"| S80
    S10 -->|"عادی و پدال"| S20
    S20["S20  X→Pick + جوهرزنی اگر لازم است"] -->|"کلیشه جوهر خورده، کاپ Park،<br/>X در Pick یا پنجره‌ی زودهنگام"| S40
    S40["S40  Flash-off"] --> S50
    S50["S50  Z Down روی کلیشه"] -->|"Z Down و X ایستاده"| S60
    S60["S60  Dwell1 → Z Up<br/>پد پر (M93)"] --> S70
    S70["S70  پد بالای ارتفاع امن<br/>شروع جوهرزنی موازی"] -->|Pre-pick| S10
    S70 -->|عادی| S80
    S80["S80  X→Print<br/>(Z زودهنگام در پنجره‌ی D550)"] -->|"X در Print یا پنجره"| S90
    S90["S90  Z Down روی قطعه"] -->|"Z Down و X ایستاده"| S100
    S100["S100  Dwell2 → Z Up<br/>شمارنده++"] --> S110
    S110["S110  پد بالای ارتفاع امن"] --> S120
    S120["S120  X→Pick (بدون انتظار رسیدن)"] --> S10
```

### سه قابلیت جدید

| قابلیت | گزینه | چه می‌کند |
|---|---|---|
| **جوهرزنی موازی** | `M500` (پیش‌فرض روشن) | بعد از برداشت، به‌محض اینکه پد از ارتفاع امن بالاتر رفت، کاپ جوهرزنی بعدی را شروع می‌کند. هم‌زمان X به سمت قطعه می‌رود |
| **هم‌پوشانی حرکت** | `M507` + `D550` | ① X بعد از عبور پد از **ارتفاع امن** راه می‌افتد و منتظر رسیدن پد به بالا نمی‌ماند. ② Z وقتی X به فاصله‌ی `D550` از مقصد رسید پایین آمدن را شروع می‌کند |
| **برداشت زودتر** | `M506` + `D552` | بعد از هر چاپ، پد فوراً از کلیشه رنگ برمی‌دارد و بالای کلیشه منتظر پدال می‌ماند. بعد از پدال فقط «X→چاپ و فرود» انجام می‌شود. اگر انتظار بیشتر از `D552` شود، رنگ خشک فرض می‌شود و پد دوباره برمی‌دارد |

### قانون طلایی هم‌پوشانی

> **وقتی پد روی سطح است، X باید ساکن باشد.**

| لایه | پیاده‌سازی |
|---|---|
| ۱. زمان‌بندی | `D550` طوری تنظیم می‌شود که X بایستد پیش از آنکه پد از ارتفاع امن پایین‌تر برود |
| ۲. توقف در ارتفاع امن | اگر X هنوز حرکت دارد و پد از **ارتفاع امن** پایین‌تر رفت ⇒ **A10**، توقف فوری |
| ۳. فرود حین حرکت | اگر سنسور Down روشن شد و X هنوز حرکت دارد ⇒ **A17**، توقف فوری |
| ۴. شروع Dwell | Dwell فقط وقتی شروع می‌شود که **پد پایین و X ایستاده** باشد (S50 و S90) |

**روش تنظیم `D550`:** با `M507 = 0` شروع کنید. بعد `M507 = 1` و `D550 = 5 mm` بگذارید و مرحله‌به‌مرحله ۵ mm اضافه کنید. هر بار چاپ را از نظر سایه و کشیدگی چک کنید. اولین باری که A10 آمد یا چاپ کشیده شد، **۲۰٪ عقب** بکشید.

### حالت‌های چاپ (D554)

| حالت | کار | پیاده‌سازی |
|---|---|---|
| **۰: ۱ پدال = ۱ چاپ** | اپراتور بین چاپ‌ها قطعه را می‌چرخاند | هر پدال یک `M94` |
| **۱: ۱ پدال = N چاپ** | چند ضرب روی همان نقطه (N = `D555`) | بعد از هر چاپ، اگر `D556 < D555` باشد، PLC خودش `M94` را Set می‌کند |
| **۲: پیوسته** | بدون پدال | `M502 = (D554 = 2)` و تایمر `T206` با مکث `D546` |

تغییر حالت روی HMI فقط وقتی دستگاه متوقف است (`M90 = 0`) مجاز است. Stop وسط یک سری N چاپی، سری را قطع می‌کند و `D556` را صفر می‌کند.

### پدال

پدال در مرحله‌های S5 تا S70 **ذخیره** می‌شود (`M94`). اگر اپراتور وسط برداشت پدال بزند، چاپ بلافاصله بعد از برداشت انجام می‌شود. در مرحله‌های چاپ (S80 به بعد) پدال نادیده گرفته می‌شود.

**زیرسکانس جوهرزنی (D1):** Y ← END با `D527`، سپس Y ← PARK با `D528`، و در پایان `M92 = 1`. شرط حرکت: `M42`، یعنی پد بالای ارتفاع امن باشد یا X بیرون از ناحیه‌ی کلیشه.

### جدول انتقال‌ها

| از | به | شرط | اینترلاک سخت |
|---|---|---|---|
| S20 | S40 | `M92 ∧ M33 ∧ (M31 ∨ M63)` | حرکت X فقط با `M40` (پد بالای ارتفاع امن) |
| S50 | S60 | `(M62 ∨ DryRun) ∧ M31` | `Y4` فقط با `M41` |
| S60 | S70 | `T200` | – |
| S70 | S10 / S80 | `M26` | |
| S80 | S90 | `M32 ∨ M64` | `M40` |
| S90 | S100 | `(M62 ∨ DryRun) ∧ M32` | `M41` شامل پرده‌ی نوری |
| S100 | S110 | `T201` | |
| S110 | S120 | `M26` | |
| S120 | S10 | فرمان حرکت صادر شد، یا X از قبل در Pick است | `M40` |

**تعریف «رسیدن»:** موقعیت واقعی داخل ±`D548` **و** `M1336 = 0`. اگر محور از قبل در مقصد باشد، فرمان حرکت صادر نمی‌شود. اگر حرکت نیمه‌کاره قطع شود، Watchdog مرحله (A16) فعال می‌شود.

## ۳-۵ حالت دستی (Manual)

شرط ورود (`M38`): `M120 = 0`، اتومات در حال اجرا نیست، هومینگ و جوهرزنی فعال نیستند، و آلارم نیست.

| فرمان | رفتار | محدودیت |
|---|---|---|
| Jog X+ و X− (M104، M105) | **Hold-to-run**. در لبه‌ی فشار، مقصد = Soft-Limit. با رها کردن، کنتاکت قطع و محور ترمز می‌شود | هوم‌نشده: حداکثر ±۵۰ mm در هر فشار و با سرعت Creep |
| Jog Y+ و Y− (M106، M107) | مثل بالا | |
| Go-To (M110 تا M113) | حرکت با سرعت دستی `D523` یا `D529` | هوم‌شده و مجوزها |
| Y Test Stroke (M117) | اجرای یک رفت و برگشت کامل جوهرزنی | |
| Z Down و Z Up (M108، M109) | Set و Reset کردن `M61` | فقط با X **ایستاده** در Pick (با Y در Park) یا Print. اگر مجوز از دست برود، `M61` خودکار Reset می‌شود |

## ۳-۶ رفتار در آلارم

| کلاس | آلارم‌ها | واکنش |
|---|---|---|
| **A** (از دست رفتن موقعیت) | A01 E-Stop، A02 و A03 درایور، A04 و A05 Over-travel، A10 پد زیر ارتفاع امن حین حرکت، A17 فرود حین حرکت X | توقف **فوری** پالس (`M1078` و `M1104`)، لغو همه‌ی سکانس‌ها، پد بالا، **حذف وضعیت هوم** |
| **A′** | A13 گارد، A14 ارتباط HMI | توقف فوری پالس. وضعیت هوم حفظ می‌شود |
| **B** | A06 هوا، A07 تا A09 مربوط به Z، A11 و A12 هوم، A15 پارامتر، A16 Timeout مرحله | لغو سکانس، رها شدن درخواست‌ها (ترمز با شیب Decel)، پد بالا |

پس از Reset:

* اگر علت آلارم هنوز باقی باشد، در اسکن بعد دوباره فعال می‌شود.
* شروع اتومات از **S5** است، یعنی اول رفتن به موقعیت شروع.
* بعد از آلارم کلاس A، **هومینگ دوباره الزامی است**.

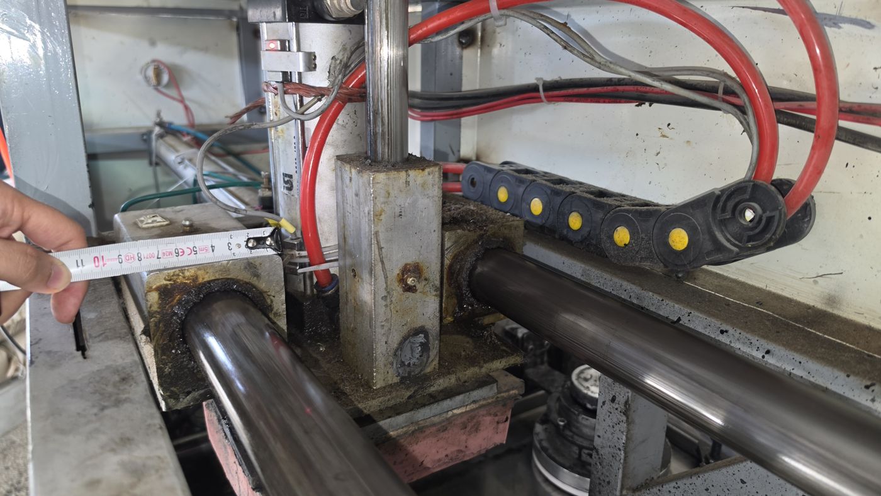
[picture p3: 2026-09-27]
docs/field_photos/x_carriage_round_shafts.jpg

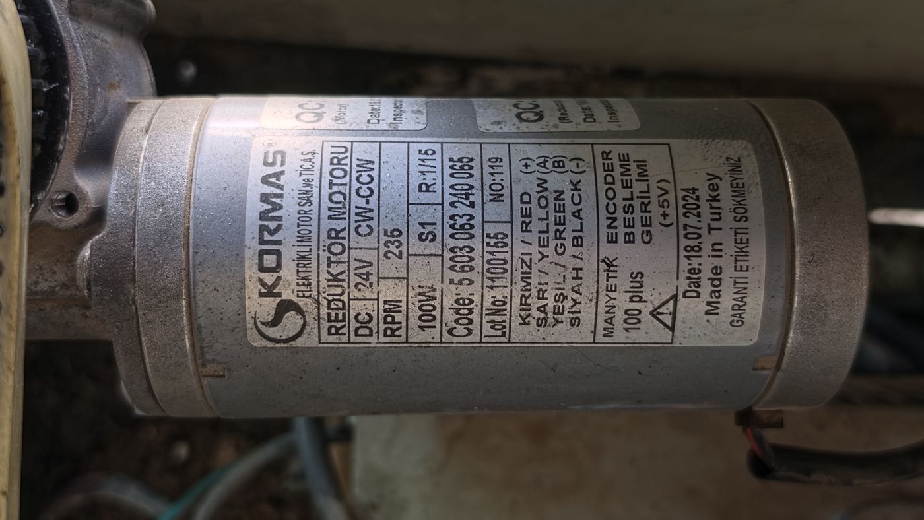
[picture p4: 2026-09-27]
docs/field_photos/y_dc_motor_kormas.jpg

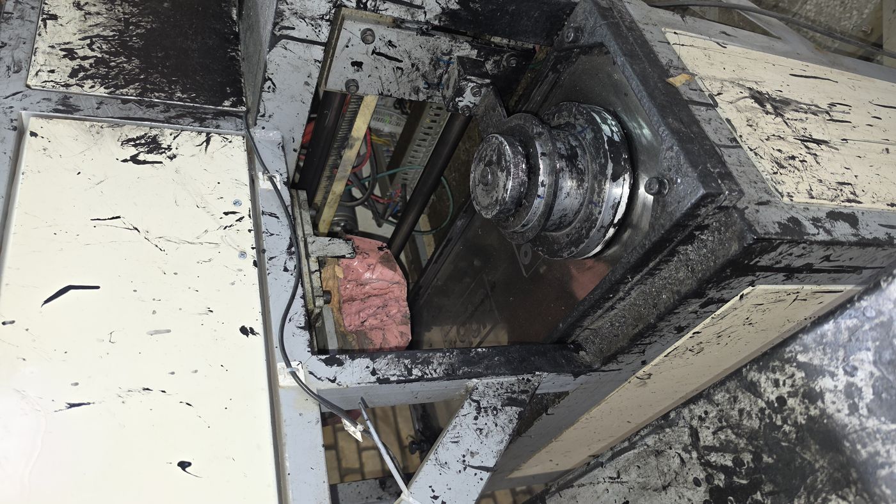
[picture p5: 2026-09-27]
docs/field_photos/cup_and_pad_front.jpg

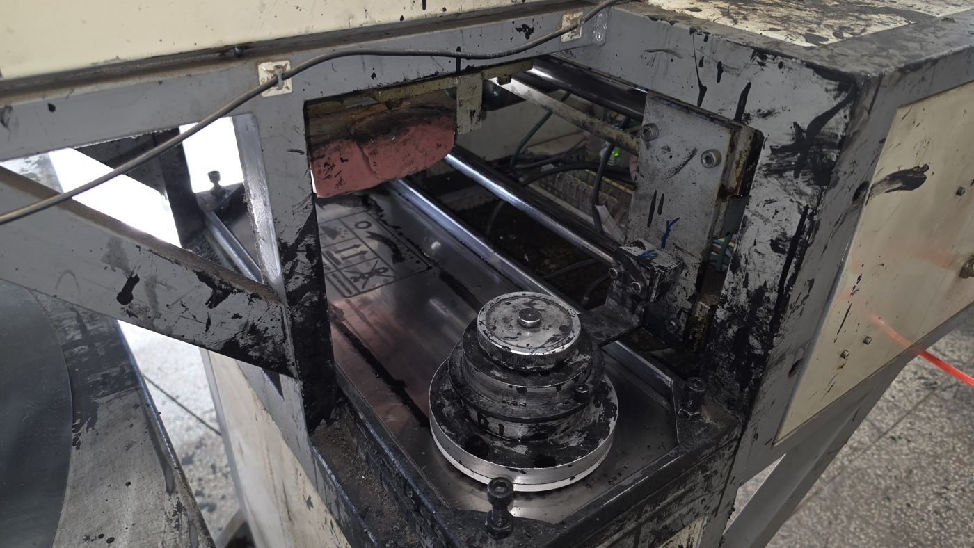
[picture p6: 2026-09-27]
docs/field_photos/cup_and_pad_side.jpg

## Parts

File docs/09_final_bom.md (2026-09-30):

# ۹. لیست خرید نهایی (طرح جدید، بر اساس داده‌های دستگاه موجود)

> این لیست جایگزین بخش ۷ است. مبنای طراحی: [بخش ۸](08_field_data_redesign.md).
> فایل Excel: [`bom/bom_final_v2.csv`](../bom/bom_final_v2.csv)

## خلاصه‌ی طرح

| محور | انتخاب |
|---|---|
| **X** | استپر کلوزلوپ ۴ N·m + گیربکس ۱:۳ + تسمه‌ی HTD5M عرض ۲۵ + دو ریل HGR20 (یا همان شفت‌های Ø45 با بوش خشک) |
| **Y** | همان استپر، مستقیم + پولی ۲۴ دندانه روی **همان تسمه‌ی ۲۰ mm فعلی** |
| **Z** | جک SC63×100 + سه سنسور القایی M12 با تسمه‌ی آهنی + شیر 3/8 + دو شیر تخلیه‌ی سریع + رگولاتور جدا + پایلوت‌چک |
| **کنترل** | DVP-28SV2 + DVP16SP + **ماژول شبکه DVPEN01-SL** + DOP-107BV + رله‌ی ایمنی + پرده‌ی نوری |

## جمع بر اساس گروه

| گروه | قیمت جهانی (USD) |
|---|---:|
| کنترل | $585 تا $876 |
| شبکه | $45 تا $330 |
| حرکت | $394 تا $534 |
| تغذیه | $124 تا $124 |
| مکانیک X | $226 تا $613 |
| مکانیک Y | $5 تا $20 |
| پنوماتیک Z | $520 تا $774 |
| سنسورها | $156 تا $232 |
| ایمنی | $918 تا $1,344 |
| تابلو | $430 تا $1,020 |
| **جمع کل** | **$3,403 تا $5,867** |

> **قیمت‌ها:** قیمت جهانی (سایت‌های مرجع خارجی)، **بدون حمل و گمرک**. ردیف‌های «برآورد» قیمت مستقیم در جستجو نداشتند.
> با دلار حدود ۲۳۱ هزار تومان، جمع کل تقریباً **786 تا 1,355 میلیون تومان** می‌شود. قیمت فعلی بازار ایران معمولاً **کمتر** از این است (بخش ۷).
> **شاسی، ساخت مکانیکی، پد، کلیشه و کاپ** در این لیست نیستند. قطعات مکانیکی و اسکلت از مدل سه‌بعدی می‌آیند: [بخش ۱۳](13_3d_design.md) و [`cad/out/parts_list.csv`](../cad/out/parts_list.csv).

## جدول کامل

| # | گروه | قطعه | مشخصات برای فروشنده | تعداد | قیمت واحد (USD) | جمع (USD) | مبنا |
|---|---|---|---|:-:|---|---:|---|
| 1 | کنترل | PLC | Delta DVP28SV11T2 (۱۶ ورودی / ۱۲ خروجی ترانزیستوری) | 1 | $182 تا $330 | $182 تا $330 | [منبع](https://www.ebay.com/itm/395576838844) |
| 2 | کنترل | HMI | Delta DOP-107BV هفت اینچ | 1 | $136 تا $169 | $136 تا $169 | [منبع](https://www.ebay.com/itm/185015742358) |
| 3 | کنترل | ماژول توسعه | Delta DVP16SP11T (۸ ورودی / ۸ خروجی) | 1 | $117 تا $127 | $117 تا $127 | [منبع](https://plc-direct.com/products/dvp16sp11t) |
| 4 | کنترل | ماژول اترنت PLC | Delta DVPEN01-SL (سمت چپ DVP-SV، Modbus TCP) | 1 | $150 تا $250 | $150 تا $250 | *برآورد* ([مرجع](https://us.rs-online.com/product/delta-electronics/dvpen01-sl/72653131/)) |
| 5 | شبکه | سوئیچ شبکه | سوئیچ صنعتی ۵ پورت DIN-Rail | 1 | $30 تا $90 | $30 تا $90 | *برآورد* |
| 6 | شبکه | کابل شبکه | Cat6 شیلددار + کانکتور (حدود ۲۰ متر) | 1 | $15 تا $40 | $15 تا $40 | *برآورد* |
| 7 | شبکه | رایانه‌ی دروازه ERP | مینی‌PC ویندوز یا لینوکس (یا رایانه‌ی موجود) | 1 | $0 تا $200 | $0 تا $200 | *برآورد* |
| 8 | حرکت | موتور X و Y + یدکی | استپر کلوزلوپ NEMA24، ۴ N·m (۴۰ kg·cm)، انکودر ۱۰۰۰ خط، با کابل انکودر | 3 | $44 تا $60 | $132 تا $180 | [منبع](https://www.oyostepper.com/goods-1263-S-Series-Nema-24-Closed-Loop-Stepper-Motor-18-Deg-40-Nm56645ozin-50A-2-Phase-with-Optical-Incremental-Encoder.html) |
| 9 | حرکت | درایور + یدکی | درایور کلوزلوپ CL57T یا HBS57، ورودی ۲۴ تا ۴۸ ولت، خروجی ALM | 3 | $54 تا $68 | $162 تا $204 | [منبع](https://www.cloudraylaser.com/products/cloudray-cl57-24-48vdc-3-6a-leadshine-closed-loop-stepper-motor-driver) |
| 10 | حرکت | گیربکس X | خورشیدی NEMA24 (فلنج ۶۰)، نسبت ۱:۳، لقی ≤ ۱۵ آرک‌دقیقه | 1 | $100 تا $150 | $100 تا $150 | *برآورد* ([مرجع](https://www.omc-stepperonline.com/nema-24-eg-series-planetary-gearbox)) |
| 11 | تغذیه | منبع ۴۸ ولت | MeanWell NDR-480-48 (۴۸V / ۱۰A) | 1 | $106 | $106 | [منبع](https://www.digikey.com/en/products/detail/mean-well-usa-inc/NDR-480-48/7705225) |
| 12 | تغذیه | منبع ۲۴ ولت | MeanWell LRS-150-24 | 1 | $18 | $18 | [منبع](https://www.digikey.com/en/products/detail/mean-well-usa-inc/LRS-150-24/7705015) |
| 13 | مکانیک X | ریل | HIWIN HGR20، طول ۱۰۶۰ mm (کورس X ۷۵ سانت) | 2 | $47 تا $83 | $94 تا $166 | *برآورد* ([مرجع](https://motionconstrained.com/store/hiwin-linear-guides/hiwin-hg-series-linear-guides/hg-rails-only/hiwin-hgr20r-linear-guideway-rail/)) |
| 14 | مکانیک X | واگن | HIWIN HGH20CA | 4 | $23 تا $83 | $92 تا $332 | [منبع](https://www.ebay.com/itm/174586829684) |
| 15 | مکانیک X | تسمه X (متر) | HTD5M عرض ۲۵ mm، پلی‌یورتان با مغزی فولادی، مدار باز | 3 | $10 تا $25 | $30 تا $75 | *برآورد* |
| 16 | مکانیک X | پولی X | ۲۴ دندانه HTD5M برای تسمه‌ی ۲۵ mm (یکی محرک، یکی هرزگرد) | 2 | $5 تا $20 | $10 تا $40 | [منبع](https://bepltd.com/products/24-5m-15-htd-pilot-bore-5m-timing-belt-pulley-24-tooth-x-15mm-wide) |
| 17 | مکانیک Y | پولی Y | ۲۴ دندانه گام ۵ mm برای تسمه‌ی ۲۰ mm (شکل دندانه مطابق تسمه‌ی فعلی) | 1 | $5 تا $20 | $5 تا $20 | [منبع](https://bepltd.com/products/24-5m-15-htd-pilot-bore-5m-timing-belt-pulley-24-tooth-x-15mm-wide) |
| 18 | پنوماتیک Z | جک Z | Airtac SC63×100 (مگنت لازم نیست) + راهنمای بیرونی مثل دستگاه فعلی | 1 | $136 تا $181 | $136 تا $181 | [منبع](https://trimantec.com/products/airtac-sc-double-acting-standard-cylinder-sc63x100s) |
| 19 | پنوماتیک Z | شیر Z | 5/2 دوبوبین سایز 3/8، 24VDC (مثل Airtac 4V320-10) | 1 | $40 تا $80 | $40 تا $80 | *برآورد* ([مرجع](https://trimantec.com/products/airtac-4v300-pneumatic-solenoid-valve-4v32010b)) |
| 20 | پنوماتیک Z | شیر تخلیه‌ی سریع | SMC AQ5000 یا معادل، 3/8 | 2 | $34 تا $61 | $68 تا $122 | [منبع](https://automationdistribution.com/aq5000-04/) |
| 21 | پنوماتیک Z | فلوکنترل | 3/8، Meter-Out | 2 | $15 تا $30 | $30 تا $60 | *برآورد* |
| 22 | پنوماتیک Z | رگولاتور Z | SMC AR30-03BG با گیج | 1 | $34 تا $63 | $34 تا $63 | [منبع](https://automationdistribution.com/smc-ar30-03bg-b/) |
| 23 | پنوماتیک Z | پایلوت‌چک | SMC ASP یا معادل | 1 | $42 تا $60 | $42 تا $60 | [منبع](https://automationdistribution.com/asp430f-02-08s/) |
| 24 | پنوماتیک Z | سنسور القایی Z | Autonics PR12-4DN (M12، 4 mm، NPN NO) روی براکت، با تسمه‌ی آهنی: بالا، ارتفاع امن (ناحیه)، پایین | 3 | $20 تا $26 | $60 تا $78 | [منبع](https://www.qfautomation.com/products/pr12-4dn) |
| 25 | پنوماتیک Z | FRL اصلی + پرشر سوئیچ | فیلتر رگولاتور و پرشر سوئیچ | 1 | $110 تا $130 | $110 تا $130 | [منبع](https://automationdistribution.com/smc-aw20-02bg/) |
| 26 | سنسورها | سنسور هوم | القایی M18 NPN (Autonics PR18-8DN) | 2 | $26 تا $28 | $52 تا $56 | [منبع](https://www.wolfautomation.com/sensor-inductive-proximity-o18mm-8mm-range-24707) |
| 27 | سنسورها | لیمیت سوئیچ | Omron D4N (دو سر هر محور) | 4 | $26 تا $44 | $104 تا $176 | [منبع](https://shop.hartfiel.com/products/D4N-1A31) |
| 28 | ایمنی | رله‌ی ایمنی | Pilz PNOZ s4 + s7.1 (یا معادل با خروجی تأخیری) | 1 | $348 تا $604 | $348 تا $604 | [منبع](https://shop.powermation.com/products/PILZ-750104) |
| 29 | ایمنی | E-Stop | Schneider XB5AS8442 | 2 | $24 تا $29 | $48 تا $58 | [منبع](https://www.tme.com/us/en-us/details/xb5as8442/panel-mount-switches-standard-22mm/schneider-electric/) |
| 30 | ایمنی | پرده‌ی نوری | نوع ۴، رزولوشن ۱۴ mm (انگشت) | 1 | $492 تا $602 | $492 تا $602 | [منبع](https://library.automationdirect.com/datasensing-sh4-light-curtain/) |
| 31 | ایمنی | کنتاکتور DC | برای قطع ۴۸ ولت درایورها | 1 | $30 تا $80 | $30 تا $80 | *برآورد* |
| 32 | تابلو | تابلو | بدنه ۶۰×۸۰ با صفحه‌ی نصب | 1 | $80 تا $200 | $80 تا $200 | *برآورد* |
| 33 | تابلو | لوازم تابلو | فیوز، ترمینال، رله، داکت، فیلتر EMI | 1 | $200 تا $450 | $200 تا $450 | *برآورد* |
| 34 | تابلو | کابل و Drag Chain | کابل شیلددار، زنجیر کابل، گلند EMC | 1 | $100 تا $250 | $100 تا $250 | *برآورد* |
| 35 | تابلو | چراغ، پدال، شستی | چراغ برج، پدال، شستی‌ها | 1 | $50 تا $120 | $50 تا $120 | *برآورد* |
| | | **جمع کل** | | | | **$3,403 تا $5,867** | |

## نکته‌های خرید

1. **سه موتور و سه درایور یکسان** بخرید: دو تا برای X و Y، و یکی **یدکی**.
2. **پولی Y:** یک تکه از تسمه‌ی فعلی را به فروشنده نشان دهید تا شکل دندانه (HTD گرد یا T5/AT5 ذوزنقه‌ای) درست باشد.
3. **قطر سوراخ پولی‌ها:** پولی X روی **شفت گیربکس** و پولی Y روی **شفت موتور** سوار می‌شود. قطر شفت را از دیتاشیت همان موتور و گیربکسی که خریدید بگیرید.
4. **ریل یا شفت:** اگر شفت‌های Ø45 فعلی را نگه می‌دارید، ردیف ۹ و ۱۰ را حذف کنید و به‌جایش **۴ بوش پلیمری خشک Ø45** (مثل igus drylin) بخرید.
5. **پرده‌ی نوری و رله‌ی ایمنی حذف نشوند.** اپراتور بعد از هر چاپ دستش را زیر پد ۱۶۰ کیلویی می‌برد.
6. **ولتاژ همه‌ی بوبین‌ها و سنسورها ۲۴ ولت DC** باشد.

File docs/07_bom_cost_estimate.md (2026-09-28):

# ۷. برآورد هزینه‌ی قطعات (BOM)

> ⚠️ **این بخش بر اساس اطلاعات اولیه (Gemini) نوشته شده است.** برای طرح جدید و قطعات نهایی، [بخش ۸](08_field_data_redesign.md) و [بخش ۹](09_final_bom.md) را ببینید. نکته‌های ایمنی، نویز و منطق کلی همچنان معتبرند.

> **تاریخ برآورد:** شهریور ۱۴۰۵ · **واحد:** میلیون تومان
> فایل قابل باز شدن در Excel: [`bom/bom_estimate.csv`](../bom/bom_estimate.csv)

## ⚠️ اعتبار اعداد (پیش از استفاده بخوانید)

* از محیط اجرای این پروژه، دسترسی مستقیم به **ترب** و بیشتر فروشگاه‌های ایرانی (پارتینه، مانا موتور و مانند آن‌ها) **مسدود بود**. اعداد از سه منبع جمع شده‌اند:
  * **user:** قیمتی که خودتان اعلام کردید (PLC و HMI).
  * **search:** قیمتی که در خلاصه‌ی نتایج جستجو از ترب و فروشگاه‌ها دیده شد. **تاریخ این قیمت‌ها معلوم نیست.** برای مثال، در نتایج جستجو برای همین PLC قیمت‌هایی از ۱۰.۵ تا ۴۰.۶ میلیون دیده شد. عدد پایین‌تر احتمالاً قدیمی است.
  * **estimate:** برآورد مهندسی من، هم‌سطح با قیمت اعلامی شما برای PLC و HMI. **این‌ها استعلام نیستند.**
* قیمت کالاهای **اصل** (SMC، Pilz، MeanWell و Leadshine) با **کپی یا چینی** معمولاً ۲ تا ۵ برابر فرق دارد. سنسور D-M9N و شیرهای SMC تقلبی زیاد دارند.
* پیش از خرید، سه قلم گران را **استعلام کتبی** بگیرید: رله‌ی ایمنی، جک Z و مجموعه‌ی موتور و درایور.

## ستون‌های دلاری

* **قیمت جهانی (USD):** قیمت‌هایی که از **سایت‌های مرجع خارجی** در نتایج جستجو دیده شد (DigiKey، RS، MISUMI، MROSupply، AutomationDirect، Automation Distribution، eBay و فروشگاه‌های رسمی)، در شهریور ۱۴۰۵ (سپتامبر ۲۰۲۶). لینک هر قلم در ستون «منبع» آمده است. قیمت‌ها **بدون حمل، گمرک و مالیات** هستند.
  * اقلامی که قیمتشان در سایت‌ها پیدا نشد با برچسب *برآورد* مشخص شده‌اند: گیربکس ۱:۳، تسمه، کنتاکتور و اقلام عمومی تابلو.
  * صفحه‌ی سایت‌ها مستقیم باز نشد (دسترسی از این محیط مسدود بود). قیمت‌ها از متن نتایج جستجو خوانده شده‌اند.
* **معادل دلاری قیمت ایران:** قیمت تومانی تقسیم بر نرخ دلار آزاد **≈ ۲۳۱٬۰۰۰ تومان** (۳۰ شهریور ۱۴۰۵).

> **نکته:** جمع قیمت‌های بازار ایران تقریباً **34٪ تا 37٪ قیمت جهانی** است. قیمت فروشگاه‌ها هنوز به نرخ روز دلار نرسیده است. با ورود بار جدید، قیمت‌ها احتمالاً به **قیمت جهانی × ۲۳۱ هزار تومان** بعلاوه‌ی هزینه‌ی واردات نزدیک می‌شوند. برای کل تجهیزات این یعنی تقریباً **702 تا 1,123 میلیون تومان** بدون هزینه‌ی واردات.

## جمع‌بندی بر اساس گروه

| گروه | قیمت جهانی (USD) | تومان ایران (میلیون) | معادل دلاری قیمت ایران |
|---|---:|---:|---:|
| کنترل | $435 تا $626 | 61.0 تا 65.0 | $265 تا $282 |
| حرکت | $256 تا $344 | 35.0 تا 60.0 | $152 تا $260 |
| تغذیه | $124 تا $124 | 7.5 تا 12.5 | $32 تا $54 |
| پنوماتیک | $587 تا $865 | 36.2 تا 66.4 | $156 تا $286 |
| سنسورها | $156 تا $232 | 5.2 تا 12.4 | $22 تا $52 |
| ایمنی | $918 تا $1,344 | 40.0 تا 86.0 | $173 تا $373 |
| مکانیک | $133 تا $306 | 9.5 تا 29.3 | $39 تا $125 |
| تابلو | $430 تا $1,020 | 43.0 تا 84.0 | $187 تا $364 |
| **جمع کل** | **$3,039 تا $4,861** | **237 تا 416** | **$1,026 تا $1,796** |

## جدول اقلام

| قلم | مدل | تعداد | قیمت جهانی واحد (USD) | جمع ردیف (USD) | منبع | معادل دلاری قیمت ایران (واحد) |
|---|---|:-:|---|---:|---|---|
| PLC | Delta DVP28SV11T2 | 1 | $182 تا $330 | $182 تا $330 | [YingZhou / PLC ERA / eBay](https://www.ebay.com/itm/395576838844) | $152 |
| HMI 7in | Delta DOP-107BV | 1 | $136 تا $169 | $136 تا $169 | [eBay (+$20–50 حمل)](https://www.ebay.com/itm/185015742358) | $87 |
| Expansion I/O 8DI/8DO | Delta DVP16SP11T | 1 | $117 تا $127 | $117 تا $127 | [WI Automation / PLC Direct](https://plc-direct.com/products/dvp16sp11t) | $26 تا $43 |
| Closed-loop driver | Leadshine CL57 | 2 | $54 تا $68 | $108 تا $136 | [Cloudray / AliExpress](https://www.cloudraylaser.com/products/cloudray-cl57-24-48vdc-3-6a-leadshine-closed-loop-stepper-motor-driver) | $35 تا $61 |
| Closed-loop motor NEMA24 4Nm | 60HSE4N | 2 | $44 | $88 | [Oyostepper 24HS40-5004D-E1000](https://www.oyostepper.com/goods-1263-S-Series-Nema-24-Closed-Loop-Stepper-Motor-18-Deg-40-Nm56645ozin-50A-2-Phase-with-Optical-Incremental-Encoder.html) | $26 تا $43 |
| Planetary gearbox 1:3 (X) | PLF60-3 | 1 | $60 تا $120 | $60 تا $120 | *یافت نشد* (برآورد) | $30 تا $52 |
| PSU 48V 10A | MeanWell NDR-480-48 / SE-600-48 | 1 | $106 | $106 | [DigiKey NDR-480-48](https://www.digikey.com/en/products/detail/mean-well-usa-inc/NDR-480-48/7705225) | $26 تا $43 |
| PSU 24V 6.5A | MeanWell LRS-150-24 | 1 | $18 | $18 | [DigiKey LRS-150-24](https://www.digikey.com/en/products/detail/mean-well-usa-inc/LRS-150-24/7705015) | $6 تا $11 |
| Guided cylinder (current) | SMC MGPM25-200 | 1 | $178 تا $332 | $178 تا $332 | [eBay / MROSupply / RS](https://us.rs-online.com/product/smc-corporation/mgpm25-200z/70605821/) | $65 تا $108 |
| 5/2 double solenoid valve | SMC SY5220 (Airtac 4V220 1-2) | 1 | $70 تا $97 | $70 تا $97 | [MISUMI / MROSupply / Southern Controls](https://www.mrosupply.com/hydraulics-and-pneumatics/6430742_sy5220-5dz-01_smc/) | $17 تا $30 |
| Speed controller meter-out | SMC AS2201F | 2 | $11 تا $15 | $22 تا $30 | [Automation Distribution](https://automationdistribution.com/as2201f-01-06s/) | $3 تا $5 |
| Hydraulic shock absorber | SMC RB1412 | 2 | $29 تا $43 | $58 تا $86 | [Mechatalk / MISUMI](https://us.misumi-ec.com/vona2/detail/221006500174/?HissuCode=RB1412) | $9 تا $17 |
| Reed/solid-state switch | SMC D-M9N | 3 | $29 تا $36 | $87 تا $108 | [Automation Distribution / MROSupply](https://automationdistribution.com/d-m9n/) | $6 تا $13 |
| FRL + pressure switch | SMC AC20 + ISE20 | 1 | $110 تا $130 | $110 تا $130 | [AW20 ($42.65) + ISE20 ($67–87)](https://automationdistribution.com/smc-aw20-02bg/) | $17 تا $35 |
| Pilot check valve (recommended) | SMC XT34 / AS-R | 1 | $42 | $42 | [SMC ASP430F (Automation Distribution)](https://automationdistribution.com/asp430f-02-08s/) | $9 تا $17 |
| Fittings + PU tube | - | 1 | $20 تا $40 | $20 تا $40 | *–* (برآورد) | $6 تا $13 |
| Inductive NPN M18 | Autonics PR18-8DN | 2 | $26 تا $28 | $52 تا $56 | [Wolf Automation / QF Automation](https://www.wolfautomation.com/sensor-inductive-proximity-o18mm-8mm-range-24707) | $7 تا $14 |
| Over-travel limit switch | Omron/Autonics | 4 | $26 تا $44 | $104 تا $176 | [Omron D4N (Hartfiel / MISUMI)](https://shop.hartfiel.com/products/D4N-1A31) | $2 تا $6 |
| Safety relay | Pilz PNOZ s4 + s7.1 | 1 | $348 تا $604 | $348 تا $604 | [PNOZ s4 ($133–364) + s7.1 ($215–240)](https://shop.powermation.com/products/PILZ-750104) | $87 تا $195 |
| E-stop 2NC | Schneider XB5AS8442 | 2 | $24 تا $29 | $48 تا $58 | [TME / Kempston / Tameson](https://www.tme.com/us/en-us/details/xb5as8442/panel-mount-switches-standard-22mm/schneider-electric/) | $4 تا $11 |
| Light curtain type 4 | Chinese brand (Sick/Omron 60-150) | 1 | $492 تا $602 | $492 تا $602 | [AutomationDirect (Contrinex / Datasensing)](https://library.automationdirect.com/datasensing-sh4-light-curtain/) | $65 تا $130 |
| DC contactor 48V | KM1 | 1 | $30 تا $80 | $30 تا $80 | *–* (برآورد) | $13 تا $26 |
| Linear rail HGR15 (Y) per m | HIWIN/HQM | 1 | $31 تا $60 | $31 تا $60 | [Motion Constrained (از $30.72)](https://motionconstrained.com/store/hiwin-linear-guides/hiwin-hg-series-linear-guides/hg-rails-only/hiwin-hgr15r-linear-guideway-rail/) | $11 تا $22 |
| Carriage HGH15CA | HIWIN/HQM | 2 | $29 تا $53 | $58 تا $106 | [PicClick / eBay](https://www.ebay.com/itm/184611756265) | $4 تا $23 |
| Timing belt HTD5M 15mm open PU steel (m) | - | 3 | $8 تا $20 | $24 تا $60 | *قیمت در نتایج نبود* (برآورد) | $4 تا $11 |
| Timing pulley 24T HTD5M-15 (drive+idler) | - | 4 | $5 تا $20 | $20 تا $80 | [BEP Ltd (از $4.80)](https://bepltd.com/products/24-5m-15-htd-pilot-bore-5m-timing-belt-pulley-24-tooth-x-15mm-wide) | $2 تا $6 |
| Enclosure 60x80 + mounting plate | - | 1 | $80 تا $200 | $80 تا $200 | *–* (برآورد) | $35 تا $65 |
| MCB/fuse/terminal/relay/duct/EMI filter | - | 1 | $200 تا $450 | $200 تا $450 | *–* (برآورد) | $87 تا $173 |
| Shielded cables + drag chain + EMC glands | - | 1 | $100 تا $250 | $100 تا $250 | *–* (برآورد) | $43 تا $87 |
| Tower lamp + pedal + push buttons | - | 1 | $50 تا $120 | $50 تا $120 | *–* (برآورد) | $22 تا $39 |
| **جمع کل** | | | | **$3,039 تا $4,861** | | **$1,026 تا $1,796** |

## اثر پیشنهادهای بخش ۱ روی هزینه

| تغییر پیشنهادی | اثر تقریبی (میلیون تومان) |
|---|---:|
| جک MGPM50 به‌جای MGPM25 | **15+ تا 25+** (قیمت جهانی MGPM50-100: [$378 تا $436](https://us.misumi-ec.com/vona2/detail/221006298493/?HissuCode=MGPM50-100Z)) |
| گیربکس ۱:۳ روی X | 7+ تا 12+ (در جدول بالا حساب شده) |
| پاور 36V به‌جای 48V | تقریباً بی‌اثر |
| شیر تک‌بوبین به‌جای دوبوبین | 0 تا 1− |
| پرده‌ی نوری و رله‌ی ایمنی | ۳۵ تا ۷۵ (در جدول حساب شده، **حذف نشود**) |

## راه‌های کاهش هزینه (بدون قربانی کردن ایمنی)

1. **پنوماتیک:** SMC اصل فقط برای جک Z و سنسورهای D-M9N. برای شیر، فلوکنترل و FRL از **Airtac** استفاده کنید. حدود ۱۰ تا ۱۵ میلیون صرفه‌جویی.
2. **ریل و واگن:** برای محور Y، برند **HQM یا چینی درجه‌یک** کافی است، چون بار کم است. HIWIN را برای محور X نگه دارید.
3. **درایور و موتور:** مجموعه‌ی کلوزلوپ **Rtelligent** یا **Leadshine نسخه‌ی اقتصادی** (مثل CS-D508 به همراه موتور مربوط) معمولاً ۳۰ تا ۴۰٪ ارزان‌تر است. فقط تطابق ورودی پالس ۲۴ ولت و خروجی ALM را چک کنید.
4. **رله‌ی ایمنی:** به‌جای ترکیب PNOZ s4 و s7.1، یک رله‌ی ایمنی با **خروجی تأخیری داخلی** (مثل PNOZ X2.8P یا معادل Omron G9SE) انتخاب کنید.
5. **از خرید PLC و HMI با قیمت بالای بازه خودداری کنید.** اختلاف فروشنده‌ها در ترب برای همین مدل تا دو برابر است. کالای **نو با گارانتی نمایندگی** را با کالای استوک یا کارکرده مقایسه نکنید.

## منابع جستجو

* [ترب: PLC دلتا DVP28SV11T2](https://torob.com/p/b2c942d9-1ee2-4880-8eed-1a58b3dac1ea/plc-%D8%AF%D9%84%D8%AA%D8%A7-%D9%85%D8%AF%D9%84-dvp28sv11t2/)
* [ترب: درایور کلوزلوپ HBS57](https://torob.com/p/41aff8d5-269a-4f77-beca-6a30a560e92d/)
* [ترب: منبع تغذیه‌ی 48V/10A](https://torob.com/p/c3d43b1a-18f7-4af6-9045-be6917785a17/)
* [emalls: MeanWell LRS-150-24](https://emalls.ir/%D9%85%D8%B4%D8%AE%D8%B5%D8%A7%D8%AA_%D9%85%D9%86%D8%A8%D8%B9-%D8%AA%D8%BA%D8%B0%DB%8C%D9%87-%D8%B3%D9%88%D8%A6%DB%8C%DA%86%DB%8C%D9%86%DA%AF-24-%D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)
* [ترب: واگن HGH15CA هایوین](https://torob.com/p/c16d2cb1-a908-4995-86b9-72f34a093e34/)
* [cncyadak: ریل HGR15 مدل HQM](https://cncyadak.com/product/%D8%B1%DB%8C%D9%84-%D8%B9%D8%B1%D8%B6-15-%D9%85%DB%8C%D9%84%DB%8C%D9%85%D8%AA%D8%B1-%D9%85%D8%AF%D9%84-hgr15-%D8%A8%D8%B1%D9%86%D8%AF-%D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)
* [دیجی‌کالا: سنسور Autonics PRL18-8DN](https://www.digikala.com/product/dkp-4277126/)
* [پارتینه: گیربکس خورشیدی](https://partineh.com/category/planetary-gearbox)
* [نرخ دلار آزاد، ۳۰ شهریور ۱۴۰۵ (اقتصادنیوز)](https://www.eghtesadnews.com/%D8%A8%D8%AE%D8%B4-%D8%A7%D8%AE%D8%A8%D8%A7%D8%B1-%D8%B7%D9%84%D8%A7-%D8%A7%D8%B1%D8%B2-40/808013-%D9%82%DB%8C%D9%85%D8%AA-%D8%AF%D9%84%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)
* [مرکز برق: جک SMC MGPM](https://www.markazbargh.com/product/smc-three-shaft-pneumatic-mgpm/)

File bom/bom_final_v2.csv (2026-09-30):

group | item | spec | qty | usd_min | usd_max | basis | source
کنترل | PLC | Delta DVP28SV11T2 (۱۶ ورودی / ۱۲ خروجی ترانزیستوری) | 1 | 182 | 330 | search | https://www.ebay.com/itm/395576838844
کنترل | HMI | Delta DOP-107BV هفت اینچ | 1 | 136 | 169 | search | https://www.ebay.com/itm/185015742358
کنترل | ماژول توسعه | Delta DVP16SP11T (۸ ورودی / ۸ خروجی) | 1 | 117 | 127 | search | https://plc-direct.com/products/dvp16sp11t
کنترل | ماژول اترنت PLC | Delta DVPEN01-SL (سمت چپ DVP-SV، Modbus TCP) | 1 | 150 | 250 | estimate | https://us.rs-online.com/product/delta-electronics/dvpen01-sl/72653131/
شبکه | سوئیچ شبکه | سوئیچ صنعتی ۵ پورت DIN-Rail | 1 | 30 | 90 | estimate
شبکه | کابل شبکه | Cat6 شیلددار + کانکتور (حدود ۲۰ متر) | 1 | 15 | 40 | estimate
شبکه | رایانه‌ی دروازه ERP | مینی‌PC ویندوز یا لینوکس (یا رایانه‌ی موجود) | 1 | 0 | 200 | estimate
حرکت | موتور X و Y + یدکی | استپر کلوزلوپ NEMA24، ۴ N·m (۴۰ kg·cm)، انکودر ۱۰۰۰ خط، با کابل انکودر | 3 | 44 | 60 | search | https://www.oyostepper.com/goods-1263-S-Series-Nema-24-Closed-Loop-Stepper-Motor-18-Deg-40-Nm56645ozin-50A-2-Phase-with-Optical-Incremental-Encoder.html
حرکت | درایور + یدکی | درایور کلوزلوپ CL57T یا HBS57، ورودی ۲۴ تا ۴۸ ولت، خروجی ALM | 3 | 54 | 68 | search | https://www.cloudraylaser.com/products/cloudray-cl57-24-48vdc-3-6a-leadshine-closed-loop-stepper-motor-driver
حرکت | گیربکس X | خورشیدی NEMA24 (فلنج ۶۰)، نسبت ۱:۳، لقی ≤ ۱۵ آرک‌دقیقه | 1 | 100 | 150 | estimate | https://www.omc-stepperonline.com/nema-24-eg-series-planetary-gearbox
تغذیه | منبع ۴۸ ولت | MeanWell NDR-480-48 (۴۸V / ۱۰A) | 1 | 106 | 106 | search | https://www.digikey.com/en/products/detail/mean-well-usa-inc/NDR-480-48/7705225
تغذیه | منبع ۲۴ ولت | MeanWell LRS-150-24 | 1 | 18 | 18 | search | https://www.digikey.com/en/products/detail/mean-well-usa-inc/LRS-150-24/7705015
مکانیک X | ریل | HIWIN HGR20، طول ۱۰۶۰ mm | 2 | 47 | 83 | estimate | https://motionconstrained.com/store/hiwin-linear-guides/hiwin-hg-series-linear-guides/hg-rails-only/hiwin-hgr20r-linear-guideway-rail/
مکانیک X | واگن | HIWIN HGH20CA | 4 | 23 | 83 | search | https://www.ebay.com/itm/174586829684
مکانیک X | تسمه X (متر) | HTD5M عرض ۲۵ mm، پلی‌یورتان با مغزی فولادی، مدار باز | 3 | 10 | 25 | estimate
مکانیک X | پولی X | ۲۴ دندانه HTD5M برای تسمه‌ی ۲۵ mm (یکی محرک، یکی هرزگرد) | 2 | 5 | 20 | search | https://bepltd.com/products/24-5m-15-htd-pilot-bore-5m-timing-belt-pulley-24-tooth-x-15mm-wide
مکانیک Y | پولی Y | ۲۴ دندانه گام ۵ mm برای تسمه‌ی ۲۰ mm (شکل دندانه مطابق تسمه‌ی فعلی) | 1 | 5 | 20 | search | https://bepltd.com/products/24-5m-15-htd-pilot-bore-5m-timing-belt-pulley-24-tooth-x-15mm-wide
پنوماتیک Z | جک Z | Airtac SC63×100 (مگنت لازم نیست) + راهنمای بیرونی مثل دستگاه فعلی | 1 | 136 | 181 | search | https://trimantec.com/products/airtac-sc-double-acting-standard-cylinder-sc63x100s
پنوماتیک Z | شیر Z | 5/2 دوبوبین سایز 3/8، 24VDC (مثل Airtac 4V320-10) | 1 | 40 | 80 | estimate | https://trimantec.com/products/airtac-4v300-pneumatic-solenoid-valve-4v32010b
پنوماتیک Z | شیر تخلیه‌ی سریع | SMC AQ5000 یا معادل، 3/8 | 2 | 34 | 61 | search | https://automationdistribution.com/aq5000-04/
پنوماتیک Z | فلوکنترل | 3/8، Meter-Out | 2 | 15 | 30 | estimate
پنوماتیک Z | رگولاتور Z | SMC AR30-03BG با گیج | 1 | 34 | 63 | search | https://automationdistribution.com/smc-ar30-03bg-b/
پنوماتیک Z | پایلوت‌چک | SMC ASP یا معادل | 1 | 42 | 60 | search | https://automationdistribution.com/asp430f-02-08s/
پنوماتیک Z | سنسور القایی Z | Autonics PR12-4DN (M12، 4 mm، NPN NO) روی براکت، با تسمه‌ی آهنی: بالا، ارتفاع امن (ناحیه)، پایین | 3 | 20 | 26 | search | https://www.qfautomation.com/products/pr12-4dn
پنوماتیک Z | FRL اصلی + پرشر سوئیچ | فیلتر رگولاتور و پرشر سوئیچ | 1 | 110 | 130 | search | https://automationdistribution.com/smc-aw20-02bg/
سنسورها | سنسور هوم | القایی M18 NPN (Autonics PR18-8DN) | 2 | 26 | 28 | search | https://www.wolfautomation.com/sensor-inductive-proximity-o18mm-8mm-range-24707
سنسورها | لیمیت سوئیچ | Omron D4N (دو سر هر محور) | 4 | 26 | 44 | search | https://shop.hartfiel.com/products/D4N-1A31
ایمنی | رله‌ی ایمنی | Pilz PNOZ s4 + s7.1 (یا معادل با خروجی تأخیری) | 1 | 348 | 604 | search | https://shop.powermation.com/products/PILZ-750104
ایمنی | E-Stop | Schneider XB5AS8442 | 2 | 24 | 29 | search | https://www.tme.com/us/en-us/details/xb5as8442/panel-mount-switches-standard-22mm/schneider-electric/
ایمنی | پرده‌ی نوری | نوع ۴، رزولوشن ۱۴ mm (انگشت) | 1 | 492 | 602 | search | https://library.automationdirect.com/datasensing-sh4-light-curtain/
ایمنی | کنتاکتور DC | برای قطع ۴۸ ولت درایورها | 1 | 30 | 80 | estimate
تابلو | تابلو | بدنه ۶۰×۸۰ با صفحه‌ی نصب | 1 | 80 | 200 | estimate
تابلو | لوازم تابلو | فیوز، ترمینال، رله، داکت، فیلتر EMI | 1 | 200 | 450 | estimate
تابلو | کابل و Drag Chain | کابل شیلددار، زنجیر کابل، گلند EMC | 1 | 100 | 250 | estimate
تابلو | چراغ، پدال، شستی | چراغ برج، پدال، شستی‌ها | 1 | 50 | 120 | estimate

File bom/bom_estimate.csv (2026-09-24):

group | item | model | qty | unit_min_MT | unit_max_MT | basis | note | usd_equiv_min | usd_equiv_max | intl_usd_min | intl_usd_max | intl_basis | intl_source | intl_url
Control | PLC | Delta DVP28SV11T2 | 1 | 35 | 35 | user | قیمت اعلامی شما (ترب 18 تا 40.6) | 152 | 152 | 182 | 330 | search | YingZhou / PLC ERA / eBay | https://www.ebay.com/itm/395576838844
Control | HMI 7in | Delta DOP-107BV | 1 | 20 | 20 | user | قیمت اعلامی شما | 87 | 87 | 136 | 169 | search | eBay (+$20–50 حمل) | https://www.ebay.com/itm/185015742358
Control | Expansion I/O 8DI/8DO | Delta DVP16SP11T | 1 | 6 | 10 | estimate | پیشنهادی | 26 | 43 | 117 | 127 | search | WI Automation / PLC Direct | https://plc-direct.com/products/dvp16sp11t
Motion | Closed-loop driver | Leadshine CL57 | 2 | 8 | 14 | estimate | کلون HBS57 در ترب از 2.45 | 35 | 61 | 54 | 68 | search | Cloudray / AliExpress | https://www.cloudraylaser.com/products/cloudray-cl57-24-48vdc-3-6a-leadshine-closed-loop-stepper-motor-driver
Motion | Closed-loop motor NEMA24 4Nm | 60HSE4N | 2 | 6 | 10 | estimate |  | 26 | 43 | 44 | 44 | search | Oyostepper 24HS40-5004D-E1000 | https://www.oyostepper.com/goods-1263-S-Series-Nema-24-Closed-Loop-Stepper-Motor-18-Deg-40-Nm56645ozin-50A-2-Phase-with-Optical-Incremental-Encoder.html
Motion | Planetary gearbox 1:3 (X) | PLF60-3 | 1 | 7 | 12 | search | SAM PLF60:3 = 6.85 | 30 | 52 | 60 | 120 | estimate | یافت نشد
Power | PSU 48V 10A | MeanWell NDR-480-48 / SE-600-48 | 1 | 6 | 10 | estimate | چینی HZS-480-48 از 1.2 | 26 | 43 | 106 | 106 | search | DigiKey NDR-480-48 | https://www.digikey.com/en/products/detail/mean-well-usa-inc/NDR-480-48/7705225
Power | PSU 24V 6.5A | MeanWell LRS-150-24 | 1 | 1.5 | 2.5 | search | آگهی قدیمی‌تر 0.78 تا 0.81 | 6 | 11 | 18 | 18 | search | DigiKey LRS-150-24 | https://www.digikey.com/en/products/detail/mean-well-usa-inc/LRS-150-24/7705015
Pneumatic | Guided cylinder (current) | SMC MGPM25-200 | 1 | 15 | 25 | estimate |  | 65 | 108 | 178 | 332 | search | eBay / MROSupply / RS | https://us.rs-online.com/product/smc-corporation/mgpm25-200z/70605821/
Pneumatic | 5/2 double solenoid valve | SMC SY5220 (Airtac 4V220 1-2) | 1 | 4 | 7 | estimate |  | 17 | 30 | 70 | 97 | search | MISUMI / MROSupply / Southern Controls | https://www.mrosupply.com/hydraulics-and-pneumatics/6430742_sy5220-5dz-01_smc/
Pneumatic | Speed controller meter-out | SMC AS2201F | 2 | 0.6 | 1.2 | estimate |  | 3 | 5 | 11 | 15 | search | Automation Distribution | https://automationdistribution.com/as2201f-01-06s/
Pneumatic | Hydraulic shock absorber | SMC RB1412 | 2 | 2 | 4 | estimate |  | 9 | 17 | 29 | 43 | search | Mechatalk / MISUMI | https://us.misumi-ec.com/vona2/detail/221006500174/?HissuCode=RB1412
Pneumatic | Reed/solid-state switch | SMC D-M9N | 3 | 1.5 | 3 | estimate | سومی برای X17 | 6 | 13 | 29 | 36 | search | Automation Distribution / MROSupply | https://automationdistribution.com/d-m9n/
Pneumatic | FRL + pressure switch | SMC AC20 + ISE20 | 1 | 4 | 8 | estimate |  | 17 | 35 | 110 | 130 | search | AW20 ($42.65) + ISE20 ($67–87) | https://automationdistribution.com/smc-aw20-02bg/
Pneumatic | Pilot check valve (recommended) | SMC XT34 / AS-R | 1 | 2 | 4 | estimate |  | 9 | 17 | 42 | 42 | search | SMC ASP430F (Automation Distribution) | https://automationdistribution.com/asp430f-02-08s/
Pneumatic | Fittings + PU tube | - | 1 | 1.5 | 3 | estimate |  | 6 | 13 | 20 | 40 | estimate | –
Sensors | Inductive NPN M18 | Autonics PR18-8DN | 2 | 1.6 | 3.2 | search | دو قیمت دیده‌شده | 7 | 14 | 26 | 28 | search | Wolf Automation / QF Automation | https://www.wolfautomation.com/sensor-inductive-proximity-o18mm-8mm-range-24707
Sensors | Over-travel limit switch | Omron/Autonics | 4 | 0.5 | 1.5 | estimate |  | 2 | 6 | 26 | 44 | search | Omron D4N (Hartfiel / MISUMI) | https://shop.hartfiel.com/products/D4N-1A31
Safety | Safety relay | Pilz PNOZ s4 + s7.1 | 1 | 20 | 45 | estimate | قیمت روز را از نماینده بگیرید | 87 | 195 | 348 | 604 | search | PNOZ s4 ($133–364) + s7.1 ($215–240) | https://shop.powermation.com/products/PILZ-750104
Safety | E-stop 2NC | Schneider XB5AS8442 | 2 | 1 | 2.5 | estimate |  | 4 | 11 | 24 | 29 | search | TME / Kempston / Tameson | https://www.tme.com/us/en-us/details/xb5as8442/panel-mount-switches-standard-22mm/schneider-electric/
Safety | Light curtain type 4 | Chinese brand (Sick/Omron 60-150) | 1 | 15 | 30 | estimate |  | 65 | 130 | 492 | 602 | search | AutomationDirect (Contrinex / Datasensing) | https://library.automationdirect.com/datasensing-sh4-light-curtain/
Safety | DC contactor 48V | KM1 | 1 | 3 | 6 | estimate |  | 13 | 26 | 30 | 80 | estimate | –
Mechanics | Linear rail HGR15 (Y) per m | HIWIN/HQM | 1 | 2.5 | 5 | search | ریل 2.56 میلیون (چینی) | 11 | 22 | 31 | 60 | search | Motion Constrained (از $30.72) | https://motionconstrained.com/store/hiwin-linear-guides/hiwin-hg-series-linear-guides/hg-rails-only/hiwin-hgr15r-linear-guideway-rail/
Mechanics | Carriage HGH15CA | HIWIN/HQM | 2 | 1 | 5.4 | search | از 1.0 (چینی) تا 5.35 (HIWIN) | 4 | 23 | 29 | 53 | search | PicClick / eBay | https://www.ebay.com/itm/184611756265
Mechanics | Timing belt HTD5M 15mm open PU steel (m) | - | 3 | 1 | 2.5 | estimate |  | 4 | 11 | 8 | 20 | estimate | قیمت در نتایج نبود
Mechanics | Timing pulley 24T HTD5M-15 (drive+idler) | - | 4 | 0.5 | 1.5 | estimate |  | 2 | 6 | 5 | 20 | search | BEP Ltd (از $4.80) | https://bepltd.com/products/24-5m-15-htd-pilot-bore-5m-timing-belt-pulley-24-tooth-x-15mm-wide
Panel | Enclosure 60x80 + mounting plate | - | 1 | 8 | 15 | estimate |  | 35 | 65 | 80 | 200 | estimate | –
Panel | MCB/fuse/terminal/relay/duct/EMI filter | - | 1 | 20 | 40 | estimate |  | 87 | 173 | 200 | 450 | estimate | –
Panel | Shielded cables + drag chain + EMC glands | - | 1 | 10 | 20 | estimate |  | 43 | 87 | 100 | 250 | estimate | –
Panel | Tower lamp + pedal + push buttons | - | 1 | 5 | 9 | estimate |  | 22 | 39 | 50 | 120 | estimate | –

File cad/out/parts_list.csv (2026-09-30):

code | name | group | kind | material | dims | qty | kg_each | kg_total | process | note
B01 | ریل HIWIN HGR20 طول 1060 | ریل‌ها | buy | - | HGR20R1060C, گام سوراخ 60 | 2 | 2.34 | 4.69 | خرید
B02 | واگن HIWIN HGH20CA | کالسکه X | buy | - | HGH20CAZ0C | 4 | 0.4 | 1.6 | خرید
B03 | گیربکس خورشیدی PLF60 1:3 | محرک X | buy | - | PLF60-3 / EG24 1:3 | 1 | 1.0 | 1.0 | خرید
B04 | استپر کلوزلوپ NEMA24 4 N·m (X) | محرک X | buy | - | 60 mm, L≈110, 4 N·m | 1 | 1.9 | 1.9 | خرید
B05 | پولی 24T HTD5M عرض 25 | محرک X | buy | - | 24-5M-25 | 2 | 0.18 | 0.36 | خرید
B06 | شافت پولی Ø14 | محرک X | buy | - | Ø14 | 2 | 0.05 | 0.1 | خرید
B07 | تسمه HTD5M عرض 25 مغزی فولادی (حلقه با دو سر در گیره) | محرک X | buy | - | HTD5M-25 PU steel | 1 | 0.3 | 0.3 | خرید
B08 | زنجیر کابل 25×50 (X) | محرک X | buy | - | 25x50 R55، طول ≈ 1.7 m | 1 | 2.0 | 2.0 | خرید
B09 | ریل HIWIN HGR15 طول 460 | ایستگاه جوهر | buy | - | HGR15R460C | 1 | 0.67 | 0.67 | خرید
B10 | واگن HIWIN HGH15CA | ایستگاه جوهر | buy | - | HGH15CAZ0C | 1 | 0.18 | 0.18 | خرید
B11 | استپر کلوزلوپ NEMA24 4 N·m (کاپ) | ایستگاه جوهر | buy | - | 60 mm, L≈110, 4 N·m | 1 | 1.9 | 1.9 | خرید
B12 | پولی 24T گام 5 عرض 20 | ایستگاه جوهر | buy | - | 24-5M-20 (مطابق تسمه‌ی فعلی) | 2 | 0.15 | 0.3 | خرید
B13 | تسمه گام 5 عرض 20 (کاپ) | ایستگاه جوهر | buy | - | 5M-20 open | 1 | 0.15 | 0.15 | خرید
B14 | شافت هرزگرد کاپ Ø8 | ایستگاه جوهر | buy | - | Ø8 | 1 | 0.02 | 0.02 | خرید
B20 | شیر 5/2 سایز 3/8 (4V320) | کالسکه X | buy | - | Airtac 4V320-10 24VDC | 1 | 0.55 | 0.55 | خرید
B21 | جک Airtac SC63×100 | هد Z | buy | - | SC63x100 (بدون مگنت کافی است) | 1 | 2.9 | 2.9 | خرید
B21F | فلنج جلو FA جک Ø63 | هد Z | buy | - | ISO 15552 MF1 Ø63 | 1 | 0.6 | 0.6 | خرید
B21R | شافت جک + مفصل شناور M16 | هد Z | buy | - | FJ M16x1.5 | 1 | 0.5 | 0.5 | خرید
B22 | سنسور القایی M12 (Autonics PR12-4DN) | هد Z | buy | - | M12، 4 mm، NPN نرمال‌باز، 10-30 VDC | 3 | 0.05 | 0.15 | خرید
B23 | شیر تخلیه‌ی سریع 3/8 | هد Z | buy | - | SMC AQ5000 | 2 | 0.25 | 0.5 | خرید
B24 | بوش خطی فلنج‌دار LMF25UU | هد Z | buy | - | LMF25UU | 2 | 0.34 | 0.68 | خرید
B25 | رینگ توقف Ø25 | هد Z | buy | - | Shaft collar 25 | 2 | 0.1 | 0.2 | خرید
B26 | پیچ تنظیم ارتفاع M12 + مهره قفل | هد Z | buy | - | M12x200 DIN 913 | 1 | 0.15 | 0.15 | خرید
B27 | پد سیلیکونی 3016 (195×140×80) | هد Z | buy | - | 3016 شیروانی | 1 | 1.8 | 1.8 | خرید
B30 | لیمیت سوئیچ Omron D4N | سنسورها | buy | - | D4N-1A31 | 4 | 0.15 | 0.6 | خرید
B31 | سنسور هوم M18 | سنسورها | buy | - | PR18-8DN | 2 | 0.06 | 0.12 | خرید
B40 | پایه‌ی ترازشو M16 | اسکلت پایین | buy | - | M16، کف Ø80، ظرفیت ≥ ۵۰۰ kg | 10 | 0.6 | 6.0 | خرید
B50 | کلیشه‌ی فولادی 580×200×10 | ایستگاه جوهر | buy | - | کلیشه‌ی ضخیم فولادی | 1 | 9.1 | 9.1 | خرید
B51 | گیره‌ی کلیشه | ایستگاه جوهر | buy | - | گیره‌ی لبه | 1 | 0.2 | 0.2 | خرید
B52 | کاپ بسته Ø140 با رینگ سرامیکی | ایستگاه جوهر | buy | - | Ø140 (مطابق کاپ فعلی) | 1 | 1.6 | 1.6 | خرید
B53 | پین فنری کاپ | ایستگاه جوهر | buy | - | Ø8 | 3 | 0.02 | 0.06 | خرید
B61 | سوئیچ ایمنی درب | ایمنی و برق | buy | - | Pilz PSEN / Schmersal | 1 | 0.1 | 0.1 | خرید
B62 | جعبه‌ی HMI + DOP-107BV | ایمنی و برق | buy | - | DOP-107BV در جعبه | 1 | 2.5 | 2.5 | خرید
B63 | E-Stop | ایمنی و برق | buy | - | XB5AS8442 | 2 | 0.2 | 0.4 | خرید
B64 | چراغ برج | ایمنی و برق | buy | - | 3 رنگ | 1 | 0.5 | 0.5 | خرید
B65 | تابلو برق 600×800×250 | ایمنی و برق | buy | - | ورق 1.5، صفحه‌ی نصب | 1 | 28.0 | 28.0 | خرید
B66 | پدال پایی | ایمنی و برق | buy | - | پدال صنعتی با قاب | 1 | 1.2 | 1.2 | خرید
B67 | FRL + پرشر سوئیچ | ایمنی و برق | buy | - | AW20 + ISE | 1 | 1.2 | 1.2 | خرید
B70 | بلبرینگ گردان (Lazy Susan) Ø500 | میز دیسک | buy | - | Ø500، ظرفیت ≥ 200 kg | 1 | 3.5 | 3.5 | خرید
B71 | حلقه‌ی مرکزگیر دیسک (قابل تعویض برای هر قطر داخلی) | میز دیسک | buy | - | POM، ارتفاع کمتر از ضخامت دیسک | 1 | 0.5 | 0.5 | خرید
B72 | دیسک پلاستیکی Ø1000/Ø500 × 2 | میز دیسک | buy | - | قطعه‌کار نمونه | 1 | 1.8 | 1.8 | خرید
B73 | پین شاخص 120° (ایندکس) | میز دیسک | buy | - | پین فنری دستی | 1 | 0.3 | 0.3 | خرید
B90 | درپوش پلاستیکی لوله | اسکلت بالا | buy | - | PE، هم‌اندازه‌ی پروفیل | 6 | 0.01 | 0.06 | خرید
F01 | پیچ آلن M5×20 ریل HGR20 | ریل‌ها | buy | - | DIN 912 M5×20 گرید 12.9 | 36 | 0.0 | 0.0 | خرید
F02 | پیچ آلن M5×25 واگن X | کالسکه X | buy | - | DIN 912 M5×25 | 16 | 0.0 | 0.0 | خرید
F03 | پیچ آلن M8×25 فلنج جک | هد Z | buy | - | DIN 912 M8×25 | 4 | 0.0 | 0.0 | خرید
F04 | پیچ آلن M6×30 بوش LMF25 (با مهره) | هد Z | buy | - | DIN 912 M6×30 + DIN 934 | 8 | 0.0 | 0.0 | خرید
F05 | پیچ آلن M6×20 صفحه‌های کناری | هد Z | buy | - | DIN 912 M6×20 | 6 | 0.0 | 0.0 | خرید
F06 | پیچ آلن M12×25 میله‌های راهنما | هد Z | buy | - | DIN 912 M12×25 | 2 | 0.0 | 0.0 | خرید
F07 | پیچ آلن M10×30 + واشر اسلاید ارتفاع | هد Z | buy | - | DIN 912 M10×30 + DIN 125 | 4 | 0.0 | 0.0 | خرید
F08 | پیچ آلن M8×20 پایه‌ی براکت‌ها | محرک X | buy | - | DIN 912 M8×20 + واشر | 8 | 0.0 | 0.0 | خرید
F09 | پیچ آلن M4×16 ریل HGR15 | ایستگاه جوهر | buy | - | DIN 912 M4×16 | 8 | 0.0 | 0.0 | خرید
F10 | پیچ آلن M4×12 واگن کاپ | ایستگاه جوهر | buy | - | DIN 912 M4×12 | 4 | 0.0 | 0.0 | خرید
F11 | پیچ آلن M12×40 + مهره و واشر (اتصال میز) | میز دیسک | buy | - | DIN 912 M12×40 + DIN 934 + DIN 125 | 16 | 0.0 | 0.0 | خرید
M01 | میله‌ی راهنمای Z Ø25 | هد Z | machined | CK45 | Ø25 h6 × 210، سخت‌کاری و کروم | 2 | 0.81 | 1.62 | تراش/فرز | سر پایین M12 به صفحه‌ی سر؛ سر بالا شیار خار
M02 | بلوک نگه‌دارنده‌ی پد | هد Z | machined | آلومینیوم 6061 | 160x80x50 | 1 | 1.73 | 1.73 | تراش/فرز | دو طرف 2× قلاویز M10 برای شیارها؛ زیر 4× M8 به صفحه‌ی پد
M10 | پایه‌ی ریل کاپ | ایستگاه جوهر | machined | St37 | 40x460x77 | 1 | 11.12 | 11.12 | تراش/فرز | رو فرز؛ قلاویز M4 گام 60 برای HGR15
M30 | صفحه‌ی گردان Ø1050 (MDF روکش‌دار یا کامپوزیت آلومینیوم) | میز دیسک | machined | MDF روکش‌دار | Ø1050 × 20 | 1 | 12.98 | 12.98 | برش CNC | سطح صاف؛ 4 سوراخ تنظیم زاویه (120°) برای چاپ سه‌تایی
P01 | صفحه‌ی رویی ایستگاه جوهر | اسکلت پایین | plate | St37 | 470x950x10 | 1 | 35.02 | 35.02 | برش لیزر/واترجت | با پیچ M8 روی قاب؛ سوراخ‌های نصب قطعات را بعد از چیدمان جای‌یابی کنید
P02 | تسمه‌ی نصب ریل X (سنگ‌خورده) | ریل‌ها | plate | CK45 | 1060x40x15 | 2 | 4.83 | 9.66 | برش + فرز + سنگ | Ø4.2 = قلاویز M5 برای ریل (گام ۶۰)؛ Ø9 = پیچ M8 به تیر؛ رو و زیر سنگ، تخت ≤ 0.02
P10 | صفحه‌ی کالسکه X | کالسکه X | plate | آلومینیوم 6061 | 280x385x15 | 1 | 3.73 | 3.73 | برش لیزر/واترجت | صفحه‌ی سبک‌شده؛ سوراخ‌های واگن M5 با فاصله‌ی 36×32 (HGH20CA)
P11 | گیره‌ی تسمه X | کالسکه X | machined | آلومینیوم 6061 | 60x34x25 | 1 | 0.14 | 0.14 | تراش/فرز
P12 | براکت زنجیر کابل X | کالسکه X | machined | St37 | 80x40x15 نبشی | 1 | 0.38 | 0.38 | تراش/فرز
P13 | صفحه‌ی سر Z | هد Z | plate | آلومینیوم 6061 | 240x120x20 | 1 | 1.51 | 1.51 | برش لیزر/واترجت | Ø12.5 پیچ M12 میله‌ها، Ø16.5 مفصل شناور، Ø10.2 قلاویز M12 پیچ تنظیم ارتفاع، Ø6.6 پیچ M6 صفحه‌های کناری
P14 | صفحه‌ی کناری اسلاید ارتفاع پد | هد Z | plate | آلومینیوم 6061 | 160x210x12 | 2 | 1.04 | 2.08 | برش لیزر/واترجت | شیار 60 mm برای تنظیم ارتفاع پد؛ لبه‌ی بالا 3× قلاویز M6
P15 | صفحه‌ی پد | هد Z | plate | آلومینیوم 6061 | 220x160x12 | 1 | 1.13 | 1.13 | برش لیزر/واترجت | 4× M8 به بلوک؛ 4× M6 برای پایه‌ی چوبی/آلومینیومی پد
P16 | تسمه‌ی آهنی سنسورهای Z | هد Z | plate | St37 | 20x40x3 | 1 | 0.02 | 0.02 | برش لیزر/واترجت | فولاد معمولی (باید آهنی باشد)؛ 2× M5 به لبه‌ی صفحه‌ی سر؛ طول آن = ناحیه‌ی امن
P17 | براکت سنسورهای Z | هد Z | plate | St37 | 50x156.5x6 | 1 | 0.33 | 0.33 | برش لیزر/واترجت | شیار 12.5 با ±5 mm تنظیم برای بدنه‌ی M12 با دو مهره؛ نقطه‌ی قطع هر سنسور را تنظیم می‌کند
P18 | زبانه‌ی براکت سنسورهای Z | هد Z | plate | St37 | 50x60x6 | 1 | 0.14 | 0.14 | برش لیزر/واترجت | جوش به براکت؛ 2× M6 به صفحه‌ی کالسکه
P20 | پایه‌ی براکت موتور X | محرک X | plate | St37 | 60x50x12 | 1 | 0.27 | 0.27 | برش لیزر/واترجت
P21 | براکت موتور X | محرک X | plate | St37 | 130x146x12 | 1 | 1.59 | 1.59 | برش لیزر/واترجت | جوش به پایه + لچکی؛ الگوی فلنج گیربکس PLF60 را با کاتالوگ تطبیق دهید
P22 | پایه‌ی براکت هرزگرد X | محرک X | plate | St37 | 60x50x12 | 1 | 0.27 | 0.27 | برش لیزر/واترجت
P23 | براکت هرزگرد X (شیار کشش) | محرک X | plate | St37 | 110x146x12 | 1 | 1.46 | 1.46 | برش لیزر/واترجت | شیار ±10 برای کشش تسمه؛ پیچ کشش M8 از لبه
P24 | سینی زنجیر کابل X | محرک X | plate | فولاد | 880x64x2 | 1 | 0.88 | 0.88 | برش + خم | ورق 2 خم U، ارتفاع لبه 30
P30 | پایه‌ی کلیشه (بستر فرزکاری‌شده) | ایستگاه جوهر | plate | St37 | 220x600x45 | 1 | 46.45 | 46.45 | فرز + سنگ | روی سطح فرز و سنگ؛ 4× پیچ M10 به صفحه‌ی رویی، گیره‌های کلیشه با M8
P31 | بازوی کاپ | ایستگاه جوهر | plate | آلومینیوم 6061 | 240x60x12 | 1 | 0.45 | 0.45 | برش لیزر/واترجت | 3× پین فنری روی کاپ؛ نگه‌دارنده‌ی کاپ باید آزاد روی کلیشه بنشیند
P32 | گیره‌ی تسمه کاپ | ایستگاه جوهر | machined | آلومینیوم 6061 | 34x50x20 | 1 | 0.09 | 0.09 | تراش/فرز
P33 | براکت موتور کاپ | ایستگاه جوهر | plate | St37 | 90x130x10 | 1 | 0.82 | 0.82 | برش لیزر/واترجت
P33F | پایه‌ی براکت موتور کاپ | ایستگاه جوهر | plate | St37 | 40x90x10 | 1 | 0.27 | 0.27 | برش لیزر/واترجت
P34 | براکت هرزگرد کاپ (شیار کشش) | ایستگاه جوهر | plate | St37 | 90x130x10 | 1 | 0.89 | 0.89 | برش لیزر/واترجت
P34F | پایه‌ی براکت هرزگرد کاپ (شیار کشش) | ایستگاه جوهر | plate | St37 | 40x90x10 | 1 | 0.27 | 0.27 | برش لیزر/واترجت
P50 | محافظ عقب (پلی‌کربنات) | محافظ‌ها | plate | پلی‌کربنات | 950x337x5 | 1 | 1.92 | 1.92 | برش لیزر/واترجت
P51 | محافظ کناری راست (پلی‌کربنات) | محافظ‌ها | plate | پلی‌کربنات | 600x337x5 | 1 | 1.21 | 1.21 | برش لیزر/واترجت
P52 | درب کناری چپ روی ایستگاه جوهر (لولایی، با سوئیچ ایمنی) | محافظ‌ها | plate | پلی‌کربنات | 600x337x5 | 1 | 1.21 | 1.21 | برش لیزر/واترجت
P53 | محافظ جلو چپ (پلی‌کربنات) | محافظ‌ها | plate | پلی‌کربنات | 420x337x5 | 1 | 0.85 | 0.85 | برش لیزر/واترجت
P54 | بازوی HMI | ایمنی و برق | machined | St37 | SHS 40x40x3 L50 + ورق | 1 | 0.63 | 0.63 | تراش/فرز
P55 | محافظ جلو راست (پلی‌کربنات) | محافظ‌ها | plate | پلی‌کربنات | 170x337x5 | 1 | 0.34 | 0.34 | برش لیزر/واترجت
P56 | محافظ جلو پایین پنجره‌ی پد (پلی‌کربنات) | محافظ‌ها | plate | پلی‌کربنات | 240x140x5 | 1 | 0.2 | 0.2 | برش لیزر/واترجت
P60 | صفحه‌ی پایه‌ی میز گردان | میز دیسک | plate | St37 | 660x660x15 | 1 | 51.02 | 51.02 | برش لیزر/واترجت | روی قاب میز؛ 8× M8 برای بلبرینگ گردان
P61 | فلنج لوله‌ی اتصال میز | میز دیسک | plate | St37 | 120x60x10 | 8 | 0.54 | 4.34 | برش لیزر/واترجت | جوش به سر لوله‌ی اتصال؛ 2× M12 به پایه‌ی دستگاه یا قاب میز
P62 | ورق کف پایه (جوشی، مهره‌ی M16 جوش پشت) | اسکلت پایین | plate | St37 | 80x80x10 | 10 | 0.48 | 4.84 | برش لیزر/واترجت
P63 | لچکی پرتال (جوشی) | اسکلت بالا | plate | St37 | 100x100x8 | 4 | 0.31 | 1.26 | برش لیزر/واترجت | جوش دو طرف
T01 | تیر ریل X (یک‌سرآزاد) | اسکلت بالا | tube | St37 | RHS 120x60x5 L=1220 | 2 | 16.28 | 32.56 | برش اره + جوش | روی پرتال عقب و ستون جلو، 660 mm بیرون‌زده؛ هر اتصال 4× M10
T02 | طولی بالای محافظ | اسکلت بالا | tube | St37 | SHS 40x40x3 L=470 | 2 | 1.64 | 3.28 | برش اره + جوش | بین پرتال عقب و ستون جلو
T03 | تیر عرضی پرتال عقب | اسکلت بالا | tube | St37 | SHS 60x60x4 L=950 | 1 | 6.68 | 6.68 | برش اره + جوش | سرتاسری روی ستون‌ها
T04 | عرضی | اسکلت پایین | tube | St37 | SHS 60x60x4 L=830 | 4 | 5.84 | 23.35 | برش اره + جوش | بین طولی‌ها
T05 | پایه | اسکلت پایین | tube | St37 | SHS 60x60x4 L=820 | 10 | 5.77 | 57.68 | برش اره + جوش | سرتاسری، دو سر گونیا
T06 | طولی میز دیسک | میز دیسک | tube | St37 | SHS 60x60x4 L=540 | 8 | 3.8 | 30.39 | برش اره + جوش
T07 | طولی | اسکلت پایین | tube | St37 | SHS 60x60x4 L=480 | 4 | 3.38 | 13.5 | برش اره + جوش | بین پایه‌ها
T08 | عرضی جلو | اسکلت پایین | tube | St37 | SHS 60x60x4 L=360 | 4 | 2.53 | 10.13 | برش اره + جوش | بین پایه‌های جلو
T09 | ستون جلو زیر تیر | اسکلت بالا | tube | St37 | SHS 60x60x4 L=337 | 4 | 2.37 | 9.48 | برش اره + جوش | ادامه‌ی پایه‌ی جلو؛ تیر X رویش پیچ می‌شود (کشش ≈ 2 kN)
T10 | ستون پرتال عقب | اسکلت بالا | tube | St37 | SHS 60x60x4 L=277 | 2 | 1.95 | 3.9 | برش اره + جوش | روی قاب پایین جوش
T11 | عرضی جلو | اسکلت پایین | tube | St37 | SHS 60x60x4 L=240 | 2 | 1.69 | 3.38 | برش اره + جوش | بین پایه‌های جلو
T12 | اتصال میز به دستگاه (پیچی) | میز دیسک | tube | St37 | SHS 60x60x4 L=210 | 4 | 1.48 | 5.91 | برش اره + جوش | دو سر ورق فلنج P61 و 4× M12؛ نیروی چاپ را داخل فولاد می‌بندد
T13 | عرضی جلو | اسکلت پایین | tube | St37 | SHS 60x60x4 L=110 | 3 | 0.77 | 2.32 | برش اره + جوش | بین پایه‌های جلو

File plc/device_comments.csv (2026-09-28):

Device | Comment
X0 | X_HOME
X1 | Y_HOME
X2 | Z_UP
X3 | Z_DOWN
X4 | X_DRV_OK
X5 | Y_DRV_OK
X6 | X_OT_OK
X7 | Y_OT_OK
X10 | ESTOP_OK
X11 | PEDAL
X12 | START_PB
X13 | STOP_PB
X14 | RESET_PB
X15 | AIR_OK
X16 | GUARD_OK
X17 | Z_DOWN_PRINT
X20 | Z_SAFE
Y0 | X_PUL
Y1 | X_DIR
Y2 | Y_PUL
Y3 | Y_DIR
Y4 | SOL_Z_DOWN
Y5 | SOL_Z_UP
Y6 | X_ENABLE
Y7 | Y_ENABLE
Y10 | LAMP_GREEN
Y11 | LAMP_AMBER
Y12 | LAMP_RED
Y13 | AIR_MAIN
M20 | SAFE_OK
M21 | ANY_ALARM
M22 | X_HOMED
M23 | Y_HOMED
M24 | ALL_HOMED
M25 | Z_UP_OK
M26 | Z_ABOVE_SAFE
M28 | STOP_POSLOSS
M29 | STOP_IMMEDIATE
M30 | X_IN_ZONE
M31 | X_AT_PICK
M32 | X_AT_PRINT
M34 | X_AT_PARK
M33 | Y_AT_PARK
M35 | Y_AT_END
M36 | ENA_RESET_PULSE
M38 | MANUAL_ENABLE
M40 | PERMIT_X
M41 | PERMIT_Z_DOWN
M42 | PERMIT_Y
M45 | X_REQ_POS
M46 | X_REQ_JOG
M47 | Y_REQ_POS
M48 | Y_REQ_JOG
M50 | X_RUN
M52 | Y_RUN
M54 | X_DZRN
M55 | Y_DZRN
M56 | Y_HOME_DONE
M57 | X_HOME_DONE
M58 | X_CH_IDLE
M59 | Y_CH_IDLE
M60 | Z_DOWN_AUTO
M61 | Z_DOWN_MAN
M62 | Z_DOWN_OK
M63 | EARLY_PICK_WINDOW
M64 | EARLY_PRINT_WINDOW
M90 | AUTO_ACTIVE
M91 | STOP_REQ
M92 | INK_READY
M93 | PAD_LOADED
M94 | PRINT_REQUEST
M95 | BATCH_DONE
M96 | X_TARGET_PICK
M97 | X_TARGET_PRINT
M99 | PRINT_DONE_PULSE
M120 | MODE_AUTO
M500 | PARALLEL_INKING
M501 | Z_DOWN2_SENSOR
M502 | CONTINUOUS
M503 | DRY_RUN
M504 | BATCH_STOP
M505 | HMI_WATCHDOG
M506 | PRE_PICK
M507 | EARLY_Z_DESCENT
M1000 | همیشه ON
M1002 | اولین اسکن
M1013 | کلاک ۱ ثانیه
M1029 | پایان پالس CH0
M1030 | CH1
M1078 | توقف فوری پالس CH0
M1104 | CH1
M1336 | در حال ارسال پالس CH0
M1337 | CH1
D0 | AUTO
D1 | INK
D2 | HOME
D3 | X_HOME
D4 | Y_HOME step
D9 | MACHINE_STATE
D10 | X target
D12 | freq
D14 | Y target
D16 | freq
D30 | X_POS
D34 | Y_POS
D50 | ALARM_WORD 1
D51 | 2
D60 | HMI heartbeat
D61 | HMI heartbeat
D90 | X_DIST_TO_GO
D98 | مرحله‌ی قبلی
D200 | X command pos
D202 | speed
D204 | Y command pos
D206 | speed
D500 | X_PICK_POS
D502 | X_PRINT_POS
D504 | X_PARK_POS (بعد از هومینگ)
D506 | X_SOFT_MAX
D508 | ناحیه‌ی کلیشه Min
D510 | Max
D512 | Y_PARK
D514 | Y_END
D516 | Y_SOFT_MAX
D518 | X_SCALE
D520 | Y_SCALE
D522 | X auto
D523 | manual
D524 | X home
D525 | creep
D526 | X_ACC
D527 | Y out
D528 | return
D529 | jog
D530 | Y home
D531 | creep
D532 | Y_ACC
D540 | DWELL1
D541 | DWELL2
D542 | FLASH_OFF
D543 | Z down
D544 | up timeout
D545 | Z_SETTLE
D546 | CONTINUOUS_PAUSE
D547 | HOME_TIMEOUT
D548 | POS_TOLERANCE
D550 | EARLY_Z_LEAD
D552 | PRE_PICK_MAX_WAIT
D560 | TOTAL
D562 | BATCH
D564 | BATCH_TARGET
D566 | PRINT_INTERVAL
D568 | PRINTS_PER_HOUR
T0 | 100 ms
T1 | 100 ms
T2 | 100 ms
T3 | 100 ms
T6 | 100 ms
T7 | 100 ms
T8 | 100 ms
T200 | 10 ms
T201 | 10 ms
T202 | 10 ms
T203 | 10 ms
T204 | 10 ms
T205 | 10 ms
T206 | 10 ms
T207 | 10 ms
T210 | 10 ms
M180 | X_STALLED
M181 | X_STALL_DIR_PLUS
M182 | Y_STALLED
M183 | Y_STALL_DIR_PLUS
M184 | X_BACKOFF_ARMED
M185 | Y_BACKOFF_ARMED
D690 | X_STALL_BACKOFF_0.1MM
D692 | Y_STALL_BACKOFF_0.1MM

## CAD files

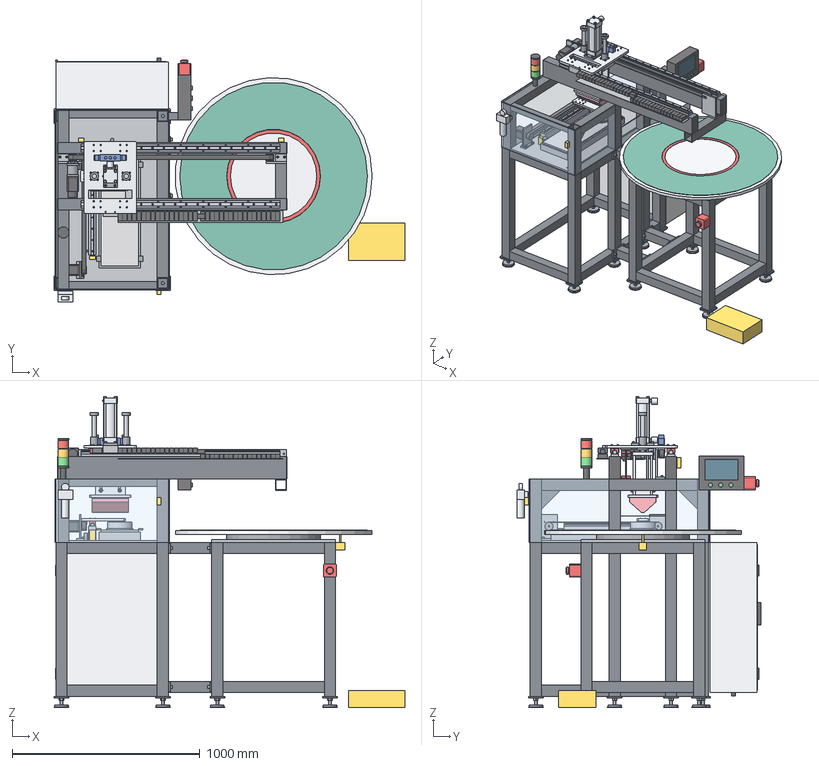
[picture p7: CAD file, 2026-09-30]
cad/out/tampo_assembly.step
1870.0 x 1301.0 x 1658.0 mm
T05_000
T05_001
T05_002
T05_003
T05_004
T05_005
T07_006
T07_007
T04_008
T08_009
T11_010
T13_011
T07_012
T07_013
T04_014
T08_015
T11_016
T13_017
T04_018
T04_019
P62_020
B40_021
P62_022
B40_023
P62_024
B40_025
P62_026
B40_027
P62_028
B40_029
P62_030
B40_031
P01_032
T10_033
T10_034
T03_035
T09_036
T09_037
T09_038
T09_039
T08_040
T13_041
T02_042
T02_043
P63_044
P63_045
P63_046
P63_047
T01_048
T01_049
B90_050
B90_051
B90_052
B90_053
B90_054
B90_055
T08_056
P02_057
B01_058
F01_059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

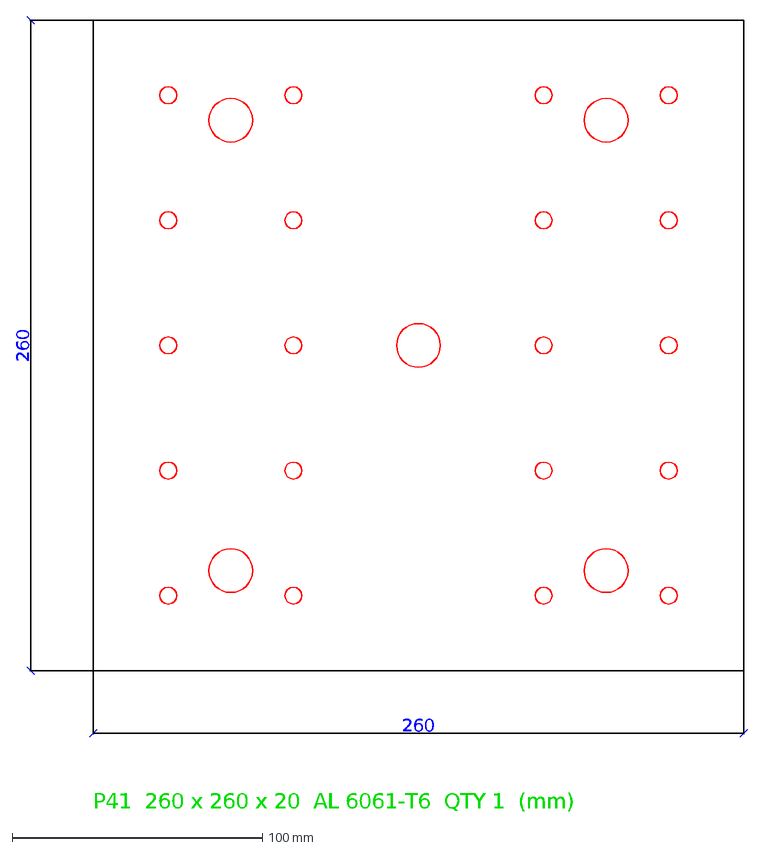
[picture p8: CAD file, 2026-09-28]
cad/out/dxf/P41.dxf
260
P41 260 x 260 x 20 AL 6061-T6 QTY 1 (mm)

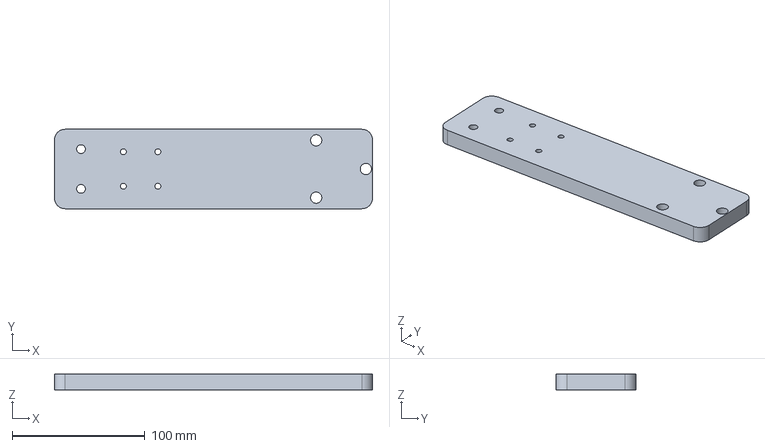
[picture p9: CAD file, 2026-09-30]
cad/out/parts_step/P31.step
240.0 x 60.0 x 12.0 mm

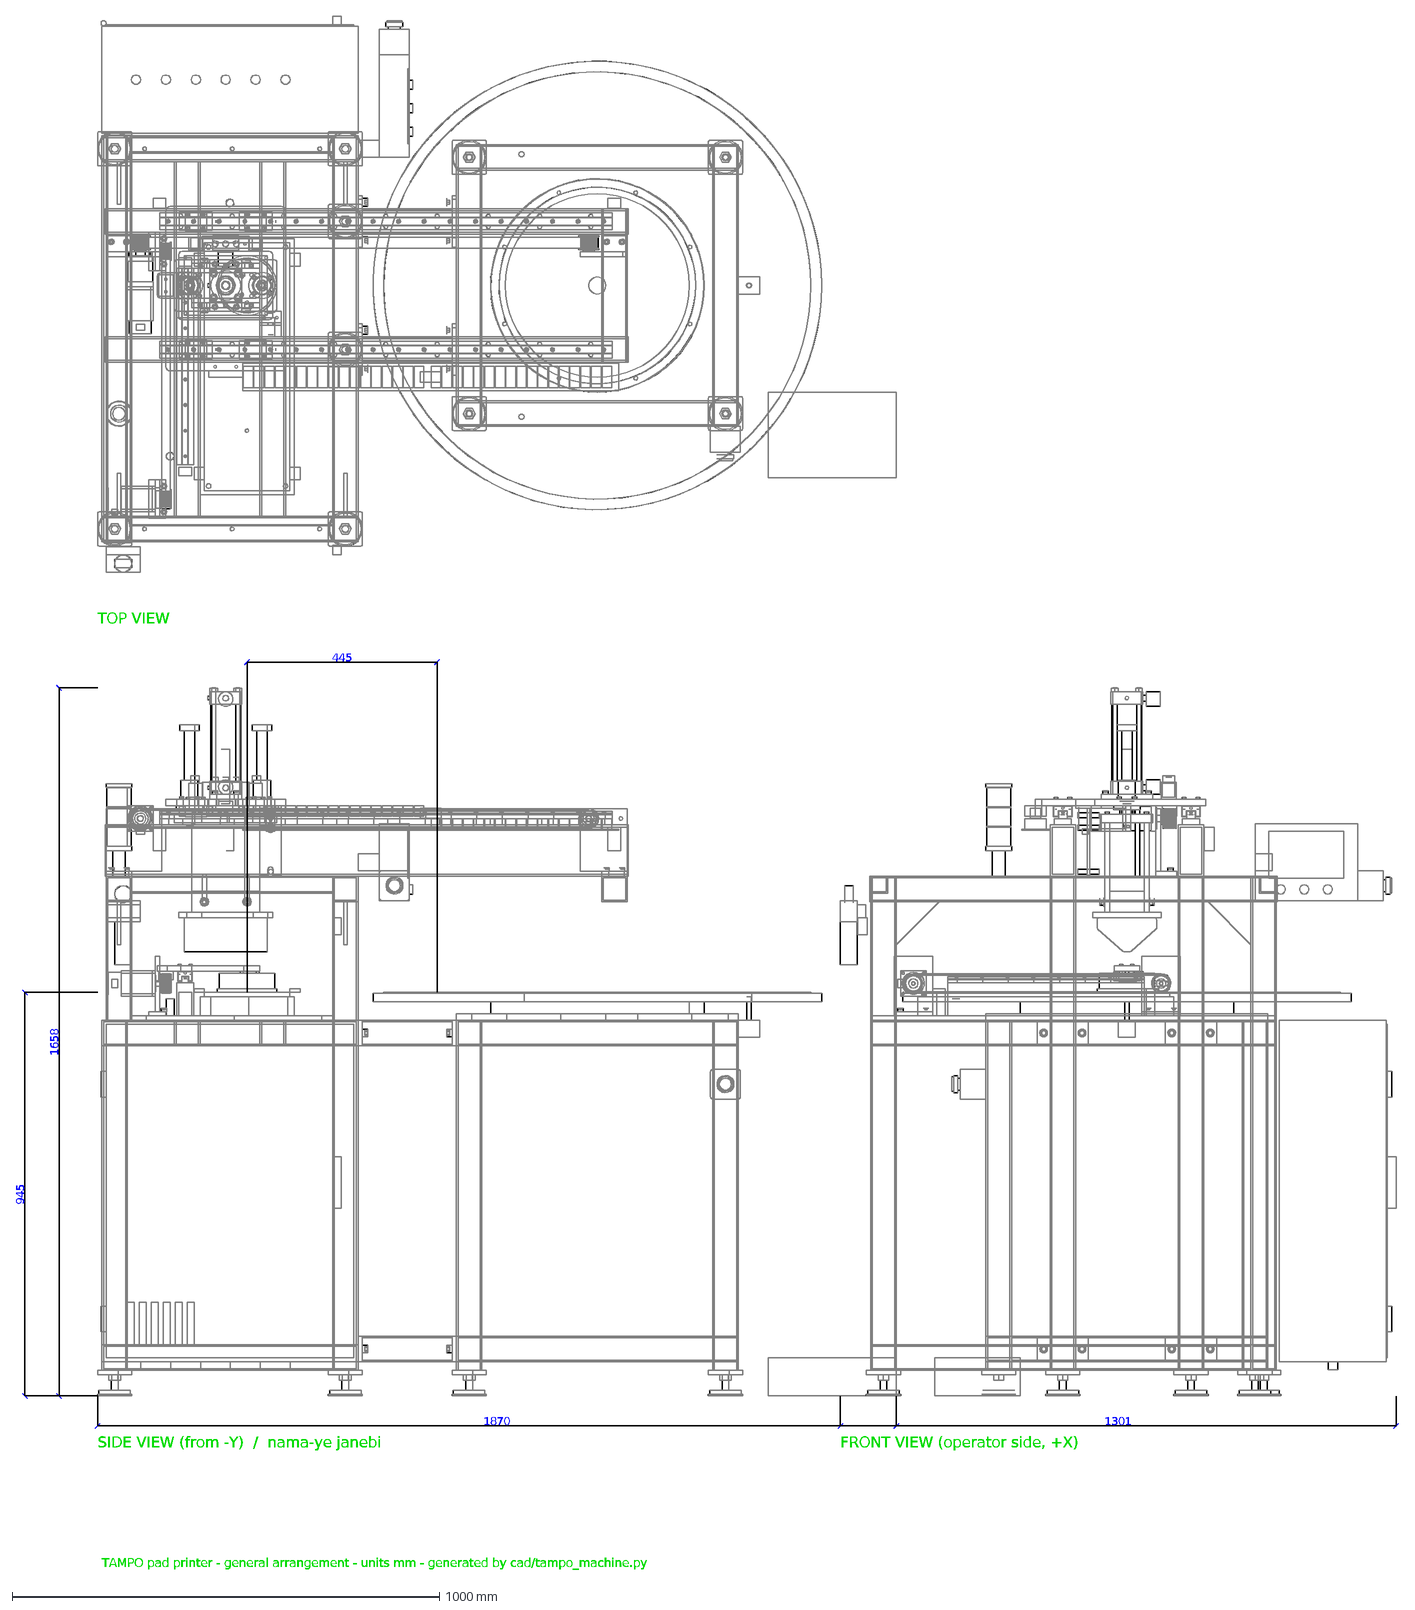
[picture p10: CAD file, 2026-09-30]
cad/out/tampo_GA.dxf
SIDE VIEW (from -Y) / nama-ye janebi
FRONT VIEW (operator side, +X)
TOP VIEW
1870
1658
945
445
1301
TAMPO pad printer - general arrangement - units mm - generated by cad/tampo_machine.py

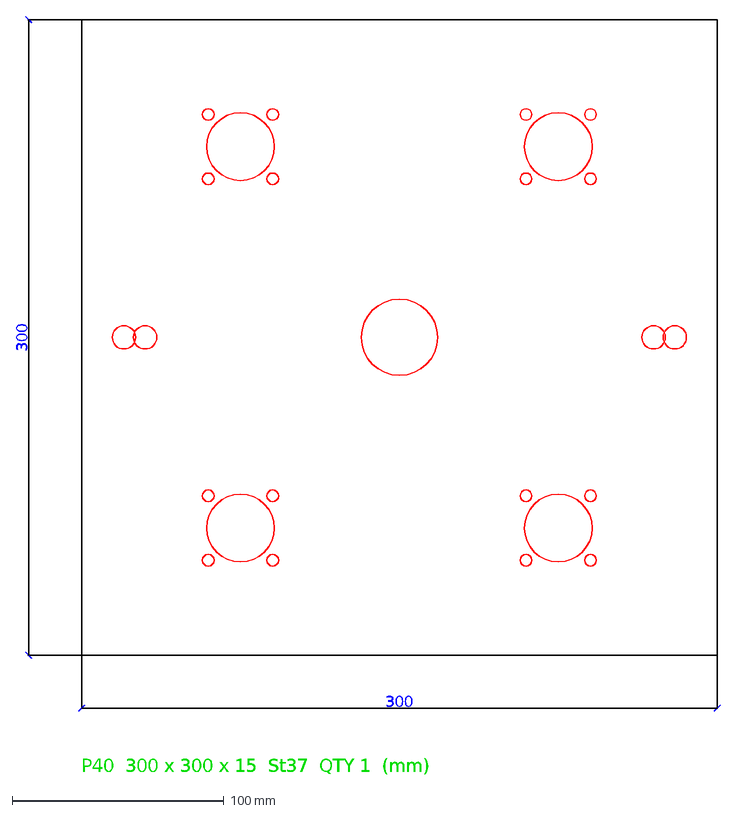
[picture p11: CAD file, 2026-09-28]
cad/out/dxf/P40.dxf
300
P40 300 x 300 x 15 St37 QTY 1 (mm)

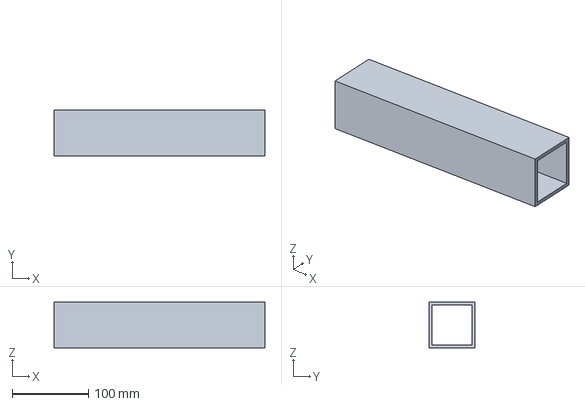
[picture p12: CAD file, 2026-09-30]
cad/out/parts_step/T10.step
277.0 x 60.0 x 60.0 mm

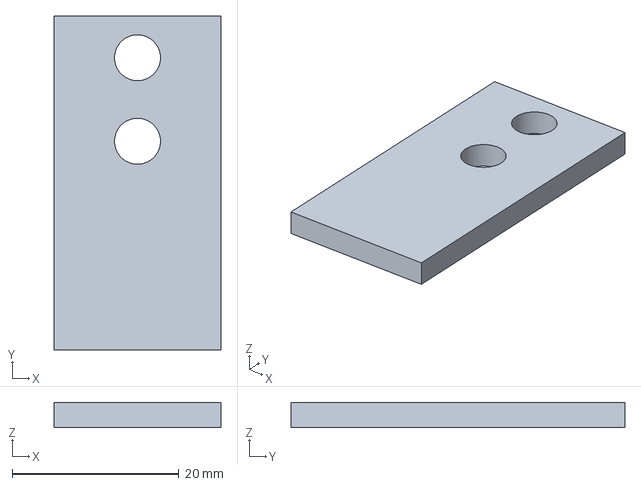
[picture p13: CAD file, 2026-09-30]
cad/out/parts_step/P16.step
20.0 x 40.0 x 3.00 mm

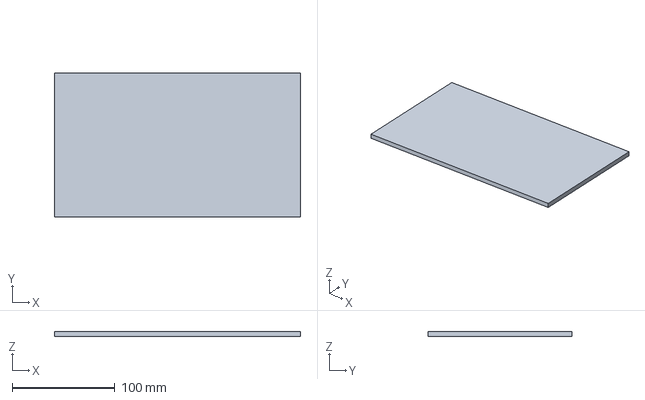
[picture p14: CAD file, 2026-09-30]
cad/out/parts_step/P56.step
240.0 x 140.0 x 5.00 mm

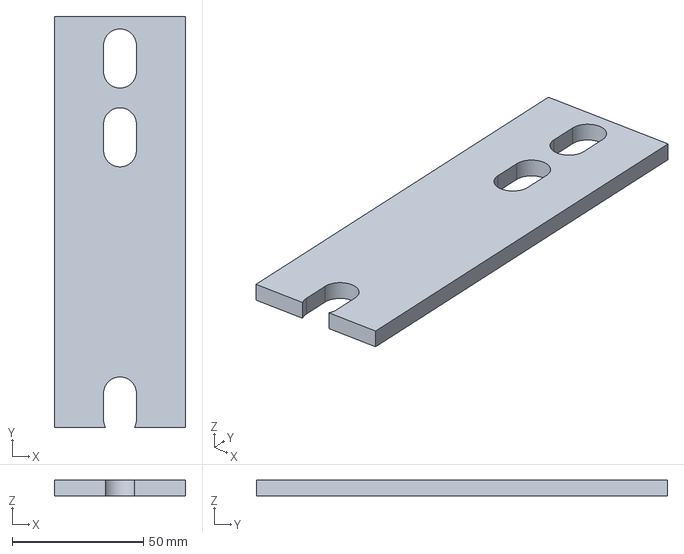
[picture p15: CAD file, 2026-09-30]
cad/out/parts_step/P17.step
50.0 x 156.5 x 6.00 mm

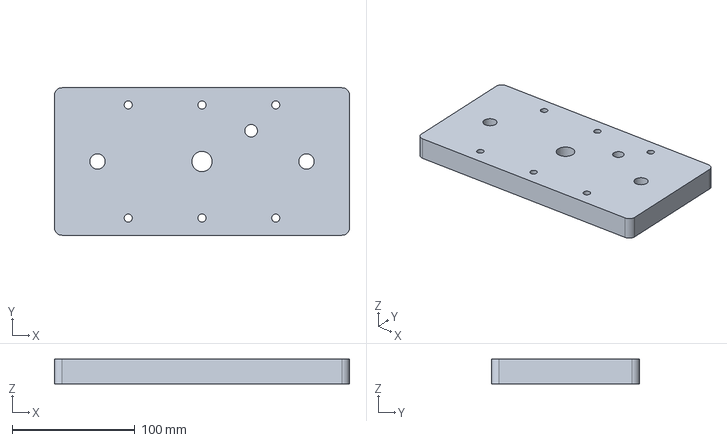
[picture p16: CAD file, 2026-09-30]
cad/out/parts_step/P13.step
240.0 x 120.0 x 20.0 mm

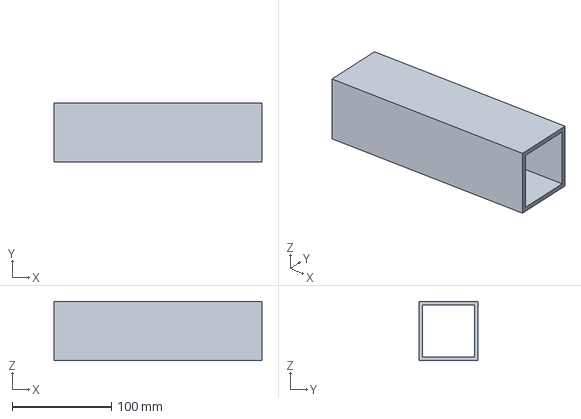
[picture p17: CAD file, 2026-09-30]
cad/out/parts_step/T12.step
210.0 x 60.0 x 60.0 mm

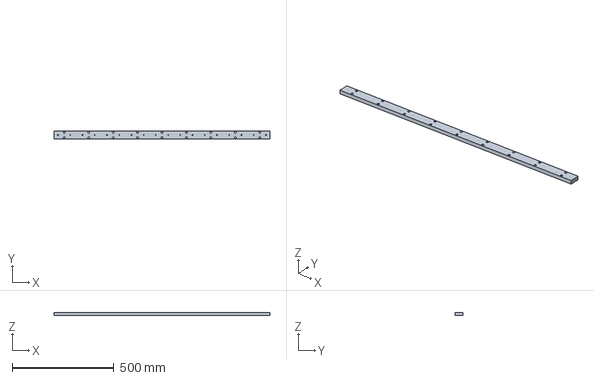
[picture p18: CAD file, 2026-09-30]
cad/out/parts_step/P02.step
1060.0 x 40.0 x 15.0 mm

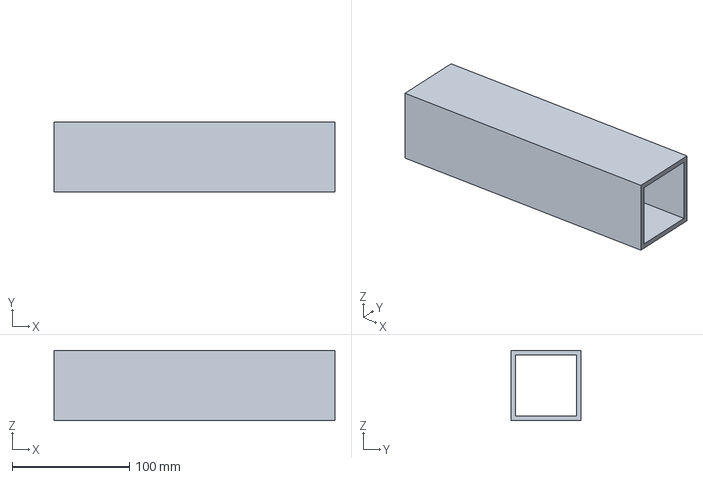
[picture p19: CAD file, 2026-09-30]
cad/out/parts_step/T11.step
240.0 x 60.0 x 60.0 mm

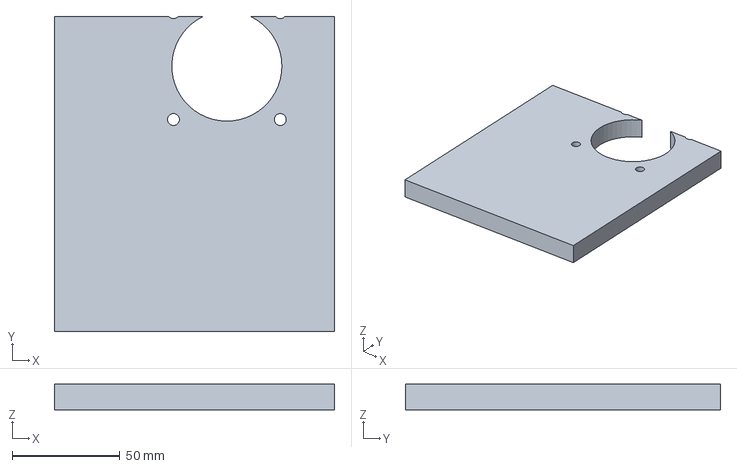
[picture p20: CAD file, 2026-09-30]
cad/out/parts_step/P21.step
130.0 x 146.0 x 12.0 mm

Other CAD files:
cad/out/parts_step/P55.step
cad/out/parts_step/P51.step
cad/out/parts_step/M10.step
cad/out/parts_step/P53.step
cad/out/dxf/P01.dxf
cad/out/dxf/P02.dxf
cad/out/dxf/P10.dxf
cad/out/dxf/P13.dxf
cad/out/dxf/P14.dxf
cad/out/dxf/P15.dxf
cad/out/dxf/P16.dxf
cad/out/dxf/P17.dxf
cad/out/dxf/P18.dxf
cad/out/dxf/P20.dxf
cad/out/dxf/P21.dxf
cad/out/dxf/P22.dxf
cad/out/dxf/P23.dxf
cad/out/dxf/P24.dxf
cad/out/dxf/P30.dxf
cad/out/dxf/P31.dxf
cad/out/dxf/P33.dxf
cad/out/dxf/P33F.dxf
cad/out/dxf/P34.dxf
cad/out/dxf/P34F.dxf
cad/out/dxf/P50.dxf
cad/out/dxf/P51.dxf
cad/out/dxf/P52.dxf
cad/out/dxf/P53.dxf
cad/out/dxf/P55.dxf
cad/out/dxf/P56.dxf
cad/out/dxf/P60.dxf
cad/out/dxf/P61.dxf
cad/out/dxf/P62.dxf
cad/out/dxf/P63.dxf
cad/out/parts_step/M01.step
cad/out/parts_step/M02.step
cad/out/parts_step/M20.step
cad/out/parts_step/M30.step
cad/out/parts_step/P01.step
cad/out/parts_step/P10.step
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

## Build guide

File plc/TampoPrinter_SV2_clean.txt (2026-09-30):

LD      M1002
MOV     K200        D1340
MOV     K200        D1352
SET     M505
DLD=    D518        K0
CALL    P9
LD      M140
ANI     M90
CALL    P9
LD<     D540        K20
MOV     K20         D540
LD>     D540        K100
MOV     K100        D540
LD<     D541        K20
MOV     K20         D541
LD>     D541        K100
MOV     K100        D541
LD>     D522        K900
MOV     K900        D522
LD>     D527        K600
MOV     K600        D527
LD>     D528        K600
MOV     K600        D528
LD<     D526        K100
MOV     K100        D526
LD<     D532        K100
MOV     K100        D532
LD>     D552        K1000
MOV     K1000       D552
LD<     D554        K0
MOV     K0          D554
LD>     D554        K2
MOV     K0          D554
LD<     D555        K1
MOV     K1          D555
LD>     D555        K9
MOV     K9          D555
DLD>    D500        D506
DMOV    D506        D500
DLD<    D500        K0
DMOV    K0          D500
DLD>    D502        D506
DMOV    D506        D502
DLD<    D502        K0
DMOV    K0          D502
DLD>    D690        K200
DMOV    K200        D690
DLD<    D690        K0
DMOV    K0          D690
DLD>    D692        K200
DMOV    K200        D692
DLD<    D692        K0
DMOV    K0          D692
DLD>    D504        D506
DOR>    D508        D510
DOR>    D514        D516
DOR>=   D512        D514
DOR<=   D518        K0
DOR<=   D520        K0
DOR<    D550        K0
OR>=    D603        D604
OR>=    D604        D605
SET     M214
LDP     X14
ORP     M102
SET     M36
ZRST    M200        M220
RST     M95
LD      M36
TMR     T7          K3
LD      T7
RST     M36
LDI     X10
SET     M200
LDI     X4
ANI     M36
SET     M201
LDI     X5
ANI     M36
SET     M202
LDI     X4
ANI     M36
AND     M50
SET     M180
LDP     M180
DAND>   D200        D30
SET     M181
LDP     M180
DAND<=  D200        D30
RST     M181
LDI     X5
ANI     M36
AND     M52
SET     M182
LDP     M182
DAND>   D204        D34
SET     M183
LDP     M182
DAND<=  D204        D34
RST     M183
LDI     X6
SET     M203
LDI     X7
SET     M204
LDI     X15
TMR     T2          K5
LD      T2
SET     M205
LD      Y4
ANI     M62
TMR     T203        D543
LD      T203
SET     M206
LDI     Y4
ANI     X2
AND     X10
AND     X15
TMR     T204        D544
LD      T204
SET     M207
LD      X2
AND     X3
LD      X2
AND     X17
ORB
LD      X20
AND     X3
ORB
LD      X2
ANI     X20
ORB
TMR     T6          K3
LD      T6
SET     M208
LD      M1336
OR      M50
ANI     M26
LD      M1337
OR      M52
ANI     M26
AND     M30
ORB
SET     M209
LD>     D3          K0
TMR     T0          D547
LD      T0
SET     M210
LD>     D4          K0
TMR     T1          D547
LD      T1
SET     M211
LDI     X16
LD      Y4
OR      M1336
OR      M1337
ANB
SET     M212
LD<>    D60         D61
OUT     M37
MOV     D60         D61
LDI     M37
AND     M505
TMR     T3          K20
LD      T3
SET     M213
ZRST    M100        M119
LD      M90
AND<>   D0          K10
AND=    D0          D98
TMR     T8          K150
LD      T8
SET     M215
LD      M1000
MOV     D0          D98
LD      M62
LD      M1336
OR      M50
ANB
SET     M216
LD      M1067
SET     M219
MOV     D1067       D683
MOV     D1068       D684
LD      M1000
MOV     K4M200      D50
MOV     K4M216      D51
LD<>    D50         K0
OR<>    D51         K0
OUT     M21
LD      M200
OR      M201
OR      M202
OR      M203
OR      M204
OR      M209
OR      M216
OUT     M28
LD      M28
OR      M212
OR      M213
OR      M218
OUT     M29
LD      M28
RST     M22
RST     M23
LD      M29
SET     M1078
SET     M1104
RST     M46
RST     M48
LDI     M29
ANI     M50
ANI     M52
ANI     M54
ANI     M55
RST     M1078
RST     M1104
LDP     M21
CALL    P11
LD      M21
RST     M90
RST     M91
RST     M92
RST     M93
RST     M94
RST     M60
RST     M61
RST     M45
RST     M47
RST     M54
RST     M55
ZRST    D0          D4
LD=     D0          K0
OR=     D0          K5
OR=     D0          K10
OR=     D0          K20
OR=     D0          K40
OR=     D0          K50
OR=     D0          K60
OR=     D0          K70
OR=     D0          K80
OR=     D0          K90
OR=     D0          K100
OR=     D0          K110
OR=     D0          K120
LD=     D1          K0
OR=     D1          K10
OR=     D1          K20
ANB
LD=     D2          K0
OR=     D2          K10
OR=     D2          K20
OR=     D2          K30
OR=     D2          K40
ANB
LD=     D3          K0
OR=     D3          K10
OR=     D3          K15
OR=     D3          K20
OR=     D3          K25
ANB
LD=     D4          K0
OR=     D4          K10
OR=     D4          K15
OR=     D4          K20
OR=     D4          K25
ANB
OUT     M170
LDI     M170
SET     M220
ZRST    D0          D4
LD      M141
RST     M90
RST     M91
RST     M92
RST     M93
RST     M94
RST     M60
RST     M61
RST     M45
RST     M46
RST     M47
RST     M48
RST     M54
RST     M55
ZRST    D0          D4
ZRST    M200        M220
RST     M1067
SET     M36
LD      X10
AND     X15
AND     X4
AND     X5
AND     X6
AND     X7
ANI     M21
OUT     M20
DLD>    D518        K0
DMUL    D1030       K10000      D40
DDIV    D40         D518        D30
DLD>    D520        K0
DMUL    D1336       K10000      D40
DDIV    D40         D520        D34
LD      M1000
DSUB    D500        D548        D70
DADD    D500        D548        D72
DZCP    D70         D72         D30     M70
DSUB    D502        D548        D74
DADD    D502        D548        D76
DZCP    D74         D76         D30     M73
DSUB    D504        D548        D78
DADD    D504        D548        D80
DZCP    D78         D80         D30     M76
DZCP    D508        D510        D30     M79
DSUB    D512        D548        D82
DADD    D512        D548        D84
DZCP    D82         D84         D34     M82
DSUB    D514        D548        D86
DADD    D514        D548        D88
DZCP    D86         D88         D34     M85
DSUB    D200        D30         D90
DABS    D90
DLD=    D200        D500
OUT     M96
DLD=    D200        D502
OUT     M97
LD      M22
AND     M23
OUT     M24
LD      M71
ANI     M1336
AND     M22
OUT     M31
LD      M74
ANI     M1336
AND     M22
OUT     M32
LD      M77
ANI     M1336
AND     M22
OUT     M34
LD      M80
ORI     M22
OUT     M30
LD      M83
ANI     M1337
AND     M23
OUT     M33
LD      M86
ANI     M1337
AND     M23
OUT     M35
LD      X2
ANI     X3
ANI     X17
ANI     Y4
TMR     T205        D545
LD      T205
OUT     M25
LD      X20
ANI     X3
ANI     X17
OUT     M26
LD      X3
LD      X17
AND     M501
ORB
OUT     M62
LD      M26
ANI     X3
ANI     X17
AND     M20
OUT     M40
LD      M26
ORI     M30
AND     M20
OUT     M42
LD      M507
AND     M96
DAND<=  D90         D550
AND     M92
OUT     M63
LD      M507
AND     M97
DAND<=  D90         D550
OUT     M64
LD      M22
CALL    P8
LDI     M22
RST     M67
LD      M31
OR      M63
AND     M33
LD      M32
OR      M64
AND     X16
ORB
AND     M24
AND     M20
ANI     M67
OUT     M41
LDI     M41
RST     M60
RST     M61
LD      X12
OR      M100
AND     M120
AND     M24
AND     M20
AND     X16
ANI     M90
AND=    D2          K0
LD      M132
ORI     M508
ANB
ANI     M95
SET     M90
RST     M91
RST     M94
MOV     K5          D0
LD      M100
ANI     M132
AND     M508
SET     M137
LD      M132
RST     M137
LDI     X13
OR      M101
ORI     M120
AND     M90
SET     M91
LDP     X11
AND     M90
AND     X16
AND<=   D0          K70
SET     M94
LD      M103
ANI     M90
AND=    D2          K0
AND     M20
MOV     K10         D2
LDI     M120
ANI     M90
AND=    D2          K0
AND=    D1          K0
AND     M20
OUT     M38
LD=     D2          K10
RST     M60
RST     M61
RST     M22
RST     M23
LD=     D2          K10
AND     M25
MOV     K20         D2
LD=     D2          K20
MOV     K10         D3
MOV     K10         D4
MOV     K30         D2
LD=     D2          K30
AND=    D3          K0
AND=    D4          K0
AND     M24
MOV     K40         D2
LD=     D2          K40
ANI     M34
ANI     M45
AND     M58
AND     M40
DMOV    D504        D200
MOV     D523        D202
SET     M45
LD=     D2          K40
ANI     M33
ANI     M47
AND     M59
AND     M42
DMOV    D512        D204
MOV     D529        D206
SET     M47
LD=     D2          K40
AND     M34
AND     M33
MOV     K0          D2
LD=     D3          K10
AND     M58
AND     M40
MPS
AND     X0
DMOV    K0          D1030
DMOV    K300        D200
MOV     D525        D202
SET     M45
MOV     K15         D3
MPP
ANI     X0
MOV     K20         D3
LD=     D3          K15
ANI     M45
AND     M58
MOV     K20         D3
LD=     D3          K20
AND     M58
AND     X0
SET     M210
LD=     D3          K20
AND     M58
ANI     X0
SET     M54
MOV     K25         D3
LD=     D3          K25
AND     M57
RST     M57
DMOV    K0          D1030
SET     M22
MOV     K0          D3
LD=     D4          K10
AND     M59
AND     M40
MPS
AND     X1
DMOV    K0          D1336
DMOV    K300        D204
MOV     D531        D206
SET     M47
MOV     K15         D4
MPP
ANI     X1
MOV     K20         D4
LD=     D4          K15
ANI     M47
AND     M59
MOV     K20         D4
LD=     D4          K20
AND     M59
AND     X1
SET     M211
LD=     D4          K20
AND     M59
ANI     X1
SET     M55
MOV     K25         D4
LD=     D4          K25
AND     M56
RST     M56
DMOV    K0          D1336
SET     M23
MOV     K0          D4
LD=     D554        K2
OUT     M502
LD=     D0          K5
ANI     M31
ANI     M45
AND     M58
AND     M40
DMOV    D500        D200
MOV     D522        D202
SET     M45
LD=     D0          K5
ANI     M33
ANI     M47
AND     M59
AND     M42
DMOV    D512        D204
MOV     D528        D206
SET     M47
LD=     D0          K5
AND     M31
AND     M33
MOV     K10         D0
LD=     D0          K10
AND     M91
RST     M90
RST     M91
RST     M93
RST     M94
MOV     K0          D556
MOV     K0          D0
LD=     D0          K10
AND     M502
TMR     T206        D546
LD=     D0          K10
AND     M93
TMR     T207        D552
LD      T207
RST     M93
LD=     D0          K10
ANI     M91
AND     M506
ANI     M93
AND     M20
MOV     K20         D0
LD=     D0          K10
ANI     M91
AND     M506
AND     M93
AND     X16
AND     M20
LD      M94
OR      T206
ANB
RST     M94
MOV     K80         D0
LD=     D0          K10
ANI     M91
ANI     M506
AND     X16
AND     M20
LD      M94
OR      T206
ANB
RST     M94
MOV     K20         D0
LD=     D0          K20
ANI     M31
ANI     M45
AND     M58
AND     M40
DMOV    D500        D200
MOV     D522        D202
SET     M45
LD=     D0          K20
ANI     M92
AND=    D1          K0
MOV     K10         D1
LD=     D0          K20
AND     M92
AND     M33
LD      M31
OR      M63
ANB
MOV     K40         D0
LD=     D0          K40
TMR     T202        D542
LD=     D0          K40
AND     T202
MOV     K50         D0
LD=     D0          K50
ANI     M503
AND     M41
SET     M60
LD=     D0          K50
LD      M62
OR      M503
ANB
AND     M31
MOV     K60         D0
LD=     D0          K60
TMR     T200        D540
LD=     D0          K60
AND     T200
RST     M60
RST     M92
SET     M93
MOV     K70         D0
LD=     D0          K70
AND     M26
AND     M500
AND=    D1          K0
MOV     K10         D1
LD=     D0          K70
AND     M26
AND     M506
MOV     K10         D0
LD=     D0          K70
AND     M26
ANI     M506
MOV     K80         D0
LD=     D0          K80
ANI     M32
ANI     M45
AND     M58
AND     M40
DMOV    D502        D200
MOV     D522        D202
SET     M45
LD=     D0          K80
LD      M32
OR      M64
ANB
MOV     K90         D0
LD=     D0          K50
OR=     D0          K90
AND     M67
SET     M217
LD=     D0          K90
ANI     M503
AND     M41
SET     M60
LD=     D0          K90
LD      M62
OR      M503
ANB
AND     M32
MOV     K100        D0
LD=     D0          K100
TMR     T201        D541
LD=     D0          K100
AND     T201
RST     M60
RST     M93
DINC    D560
DINC    D562
MOV     T210        D566
MOV     K0          D567
SET     M99
INC     D556
MOV     K110        D0
LD      M99
AND=    D554        K1
AND<    D556        D555
ANI     M91
SET     M94
LD      M99
LD<>    D554        K1
OR>=    D556        D555
OR      M91
ANB
MOV     K0          D556
LD=     D0          K110
AND     M26
MOV     K120        D0
LD=     D0          K120
ANI     M31
ANI     M45
AND     M58
AND     M40
DMOV    D500        D200
MOV     D522        D202
SET     M45
MOV     K10         D0
LD=     D0          K120
AND     M31
MOV     K10         D0
LD      M99
AND>    D566        K0
DDIV    K360000     D566        D570
MOV     D570        D568
LD      M504
DAND>=  D562        D564
DAND>   D564        K0
SET     M95
SET     M91
LD      M99
AND     M132
DINC    D606
INC     D3040E1
LD      M99
DINC    D611
LD      M90
ANI     M99
TMR     T210        K32767
LD      M99
RST     M99
LD=     D1          K10
ANI     M35
ANI     M47
AND     M59
AND     M42
DMOV    D514        D204
MOV     D527        D206
SET     M47
LD=     D1          K10
AND     M35
MOV     K20         D1
LD=     D1          K20
ANI     M33
ANI     M47
AND     M59
AND     M42
DMOV    D512        D204
MOV     D528        D206
SET     M47
LD=     D1          K20
AND     M33
SET     M92
MOV     K0          D1
LDP     M104
AND     M38
AND     M58
AND     M40
AND     M22
DMOV    D506        D200
MOV     D523        D202
SET     M46
CALL    P2
LDP     M104
AND     M38
AND     M58
AND     M40
ANI     M22
DADD    D30         K500        D200
MOV     D525        D202
SET     M46
LDP     M105
AND     M38
AND     M58
AND     M40
AND     M22
DMOV    K0          D200
MOV     D523        D202
SET     M46
CALL    P3
LDP     M105
AND     M38
AND     M58
AND     M40
ANI     M22
DSUB    D30         K500        D200
MOV     D525        D202
SET     M46
LDI     M104
ANI     M105
ORI     M38
RST     M46
LDP     M106
AND     M38
AND     M59
AND     M42
AND     M23
DMOV    D516        D204
MOV     D529        D206
SET     M48
CALL    P6
LDP     M106
AND     M38
AND     M59
AND     M42
ANI     M23
DADD    D34         K500        D204
MOV     D531        D206
SET     M48
LDP     M107
AND     M38
AND     M59
AND     M42
AND     M23
DMOV    K0          D204
MOV     D529        D206
SET     M48
CALL    P7
LDP     M107
AND     M38
AND     M59
AND     M42
ANI     M23
DSUB    D34         K500        D204
MOV     D531        D206
SET     M48
LDI     M106
ANI     M107
ORI     M38
RST     M48
LDP     X14
ORP     M102
AND     M180
SET     M184
LDP     X14
ORP     M102
AND     M182
SET     M185
LD      M184
ANI     M36
AND     X4
AND     M58
AND     M40
ANI     M45
AND     M181
DSUB    D30         D690        D200
LD      M184
ANI     M36
AND     X4
AND     M58
AND     M40
ANI     M45
ANI     M181
DADD    D30         D690        D200
LD      M184
ANI     M36
AND     X4
AND     M58
AND     M40
ANI     M45
MOV     D525        D202
SET     M45
RST     M184
RST     M180
LD      M185
ANI     M36
AND     X5
AND     M59
AND     M42
ANI     M47
AND     M183
DSUB    D34         D692        D204
LD      M185
ANI     M36
AND     X5
AND     M59
AND     M42
ANI     M47
ANI     M183
DADD    D34         D692        D204
LD      M185
ANI     M36
AND     X5
AND     M59
AND     M42
ANI     M47
MOV     D531        D206
SET     M47
RST     M185
RST     M182
LD      M110
AND     M38
AND     M24
AND     M58
AND     M40
ANI     M45
DMOV    D500        D200
MOV     D523        D202
SET     M45
LD      M111
AND     M38
AND     M24
AND     M58
AND     M40
ANI     M45
DMOV    D502        D200
MOV     D523        D202
SET     M45
LD      M112
AND     M38
AND     M24
AND     M59
AND     M42
ANI     M47
DMOV    D512        D204
MOV     D529        D206
SET     M47
LD      M113
AND     M38
AND     M24
AND     M59
AND     M42
ANI     M47
DMOV    D514        D204
MOV     D529        D206
SET     M47
LD      M117
AND     M38
AND     M24
AND=    D1          K0
MOV     K10         D1
LD      M108
AND     M38
AND     M41
ANI     M1336
SET     M61
LD      M109
ORI     M38
RST     M61
LD      M45
OR      M46
OUT     M50
LD      M47
OR      M48
OUT     M52
LD      M1000
DMUL    D200        D518        D40
DDIV    D40         K10000      D44
DMOV    D44         D10
MOV     D202        D48
MOV     K0          D49
DMUL    D48         D518        D40
DDIV    D40         K1000       D44
DMOV    D44         D12
MOV     D524        D48
DMUL    D48         D518        D40
DDIV    D40         K1000       D44
DMOV    D44         D18
MOV     D525        D48
DMUL    D48         D518        D40
DDIV    D40         K1000       D44
DMOV    D44         D20
MOV     D526        D1343
DMUL    D204        D520        D40
DDIV    D40         K10000      D44
DMOV    D44         D14
MOV     D206        D48
DMUL    D48         D520        D40
DDIV    D40         K1000       D44
DMOV    D44         D16
MOV     D530        D48
DMUL    D48         D520        D40
DDIV    D40         K1000       D44
DMOV    D44         D22
MOV     D531        D48
DMUL    D48         D520        D40
DDIV    D40         K1000       D44
DMOV    D44         D24
MOV     D532        D1353
LD      M22
CALL    P4
LDI     M22
RST     M68
RST     M66
LD      M23
CALL    P5
LDI     M23
RST     M69
RST     M65
LD      M45
AND     M68
SET     M217
RST     M45
LD      M47
AND     M69
SET     M217
RST     M47
LDP     M66
AND     M22
LDP     M65
AND     M23
ORB
SET     M218
LD      M50
AND     M40
ANI     M54
ANI     M29
DDRVA   D10         D12         Y0      Y1
LD      M54
AND     M40
ANI     M50
ANI     M29
DZRN    D18         D20         X0      Y0
LDI     M50
ANI     M54
ANI     M1336
OUT     M58
LD      M1029
MPS
AND     M54
RST     M54
SET     M57
MRD
AND     M50
RST     M45
MPP
RST     M1029
LD      M52
AND     M42
ANI     M55
ANI     M29
DDRVA   D14         D16         Y2      Y3
LD      M55
AND     M40
ANI     M52
ANI     M29
DZRN    D22         D24         X1      Y2
LDI     M52
ANI     M55
ANI     M1337
OUT     M59
LD      M1030
MPS
AND     M55
RST     M55
SET     M56
MRD
AND     M52
RST     M47
MPP
RST     M1030
LD      M60
OR      M61
AND     M41
OUT     Y4
LDI     Y4
OUT     Y5
LD      X10
ANI     M36
OUT     Y6
OUT     Y7
LD      M90
LD      M24
ANI     M90
AND     M1013
ORB
ANI     M21
OUT     Y10
LDI     M24
OR      M95
ORI     M120
ANI     M21
OUT     Y11
LD      M21
OUT     Y12
LDI     M119
OUT     Y13
LDI     M24
OUT     M150
LD      M21
OUT     M151
LDI     M120
OUT     M152
LDI     X16
OUT     M153
LDI     X15
OUT     M154
LDI     X10
OUT     M155
LD      M508
ANI     M132
OUT     M156
LDI     M26
OUT     M157
LD>     D2          K0
OUT     M158
LD      M68
OUT     M159
LD      M69
OUT     M160
LD      M67
OUT     M161
LD      M219
OUT     M162
LD      M1000
MOV     K4M150      D680
LD      M1000
MOV     K0          D9
LD      M24
MOV     K2          D9
LD>     D2          K0
MOV     K1          D9
LD      M90
MOV     K3          D9
LD      M91
MOV     K4          D9
LD      M21
MOV     K5          D9
LD      M115
DMOV    K0          D560
LD      M116
DMOV    K0          D562
RST     M95
LD      M1000
RST     M100
RST     M101
RST     M102
RST     M103
RST     M108
RST     M109
RST     M110
RST     M111
RST     M112
RST     M113
RST     M115
RST     M116
RST     M117
RST     M140
RST     M141
LD      M1000
MOV     D626        E1
MUL     D1315       K100        D620
ADD     D620        D1314       D620
MUL     D1317       K100        D630
ADD     D630        D1316       D623
MOV     K3          D622
LD>=    D620        D603
AND<    D620        D604
MOV     K1          D622
LD>=    D620        D604
AND<    D620        D605
MOV     K2          D622
LD<>    D622        D602
OUT     M134
LD      M134
AND     M132
CALL    P1
LD      M134
ZRST    D3040       D3079
DMOV    K0          D611
MOV     D622        D602
DMOV    K0          D606
MOV     D620        D608
MOV     D623        D609
MOV     D1319       D610
LDP     M130
OUT     M135
LDI     M135
CJ      P10
LD      M1000
MOV     K-1         D625
MOV     K0          E0
FOR     K40
LD=     D3000E0     D600
AND>    D600        K0
MOV     E0          D625
LD      M1000
INC     E0
NEXT
P10
LD      M135
AND>=   D625        K0
OUT     M136
LD      M135
AND<    D625        K0
SET     M133
LD      M133
TMR     T208        K300
LD      T208
RST     M133
LD      M136
AND     M132
CALL    P1
LD      M136
RST     M133
SET     M132
MOV     D600        D601
MOV     D625        D626
MOV     D625        E1
DMOV    K0          D606
MOV     D620        D608
MOV     D623        D609
MOV     D1319       D610
MOV     K0          D600
LDP     M131
AND     M132
CALL    P1
LDP     M131
RST     M132
MOV     K0          D601
LD      M1000
RST     M130
RST     M131
LD      M132
MOV     D3040E1     D616
LDI     M132
MOV     K0          D616
LD      M1000
MOV     D9          D3080
MOV     D601        D3081
MOV     D602        D3082
DMOV    D606        D3083
DMOV    D611        D3085
DMOV    D560        D3087
MOV     D568        D3089
MOV     D50         D3090
MOV     D51         D3091
MOV     D554        D3092
MOV     D3097       D3093
MOV     D627        D3094
MOV     D616        D3095
FEND
P1
LD      M1000
MUL     D627        K10         D628
MOV     D628        E2
MOV     D601        D3100E2
MOV     D602        D3101E2
MOV     D609        D3102E2
MOV     D610        D3103E2
MOV     D608        D3104E2
MOV     D620        D3105E2
DMOV    D606        D3106E2
INC     D3097
MOV     D3097       D3108E2
MOV     K0          D3109E2
INC     D627
LD>=    D627        K64
MOV     K0          D627
SRET
P2
LD      M1000
MOV     K0          E3
FOR     K4
LD      M1000
RST     M171
DLD>    D642E3      D640E3
DAND>   D640E3      D30
SET     M171
DSUB    D640E3      D672        D678
LD      M171
DAND<   D678        D200
DMOV    D678        D200
LD      M1000
ADD     E3          K4          E3
NEXT
DLD<    D200        D30
DMOV    D30         D200
SRET
P3
LD      M1000
MOV     K0          E3
FOR     K4
LD      M1000
RST     M171
DLD>    D642E3      D640E3
DAND<   D642E3      D30
SET     M171
DADD    D642E3      D672        D678
LD      M171
DAND>   D678        D200
DMOV    D678        D200
LD      M1000
ADD     E3          K4          E3
NEXT
DLD>    D200        D30
DMOV    D30         D200
SRET
P4
LD      M1000
RST     M68
RST     M66
DMOV    D30         D674
DMOV    D200        D676
DLD<    D30         D200
DMOV    D200        D674
DMOV    D30         D676
LD      M1000
MOV     K0          E3
FOR     K4
DLD>    D642E3      D640E3
DAND>=  D674        D640E3
DAND<=  D676        D642E3
SET     M68
DLD>    D642E3      D640E3
DAND>=  D30         D640E3
DAND<=  D30         D642E3
SET     M66
LD      M1000
ADD     E3          K4          E3
NEXT
SRET
P5
LD      M1000
RST     M69
RST     M65
DMOV    D34         D674
DMOV    D204        D676
DLD<    D34         D204
DMOV    D204        D674
DMOV    D34         D676
LD      M1000
MOV     K0          E3
FOR     K2
DLD>    D658E3      D656E3
DAND>=  D674        D656E3
DAND<=  D676        D658E3
SET     M69
DLD>    D658E3      D656E3
DAND>=  D34         D656E3
DAND<=  D34         D658E3
SET     M65
LD      M1000
ADD     E3          K4          E3
NEXT
SRET
P6
LD      M1000
MOV     K0          E3
FOR     K2
LD      M1000
RST     M171
DLD>    D658E3      D656E3
DAND>   D656E3      D34
SET     M171
DSUB    D656E3      D672        D678
LD      M171
DAND<   D678        D204
DMOV    D678        D204
LD      M1000
ADD     E3          K4          E3
NEXT
DLD<    D204        D34
DMOV    D34         D204
SRET
P7
LD      M1000
MOV     K0          E3
FOR     K2
LD      M1000
RST     M171
DLD>    D658E3      D656E3
DAND<   D658E3      D34
SET     M171
DADD    D658E3      D672        D678
LD      M171
DAND>   D678        D204
DMOV    D678        D204
LD      M1000
ADD     E3          K4          E3
NEXT
DLD>    D204        D34
DMOV    D34         D204
SRET
P8
LD      M1000
RST     M67
MOV     K0          E3
FOR     K2
DLD>    D666E3      D664E3
DAND>=  D30         D664E3
DAND<=  D30         D666E3
SET     M67
LD      M1000
ADD     E3          K4          E3
NEXT
SRET
P11
LD      M1000
MOV     K0          D685
MOV     K0          E4
FOR     K21
LD      M200E4
AND=    D685        K0
MOV     E4          D685
INC     D685
LD      M1000
INC     E4
NEXT
LD      M1000
MUL     D681        K8          D686
MOV     D686        E5
MOV     D685        D3750E5
MOV     D0          D3751E5
MOV     D1          D3752E5
MOV     D2          D3753E5
MOV     D620        D3754E5
MOV     D623        D3755E5
MOV     D30         D3756E5
MOV     D680        D3757E5
INC     D682
INC     D681
LD>=    D681        K16
MOV     K0          D681
SRET
P9
LD      M1000
DMOV    K100000     D518
DMOV    K33333      D520
DMOV    K500        D500
DMOV    K4950       D502
DMOV    K500        D504
DMOV    K7500       D506
DMOV    K0          D508
DMOV    K2000       D510
DMOV    K50         D512
DMOV    K3500       D514
DMOV    K3750       D516
DMOV    K50         D690
DMOV    K50         D692
MOV     K800        D522
MOV     K100        D523
MOV     K60         D524
MOV     K8          D525
MOV     K300        D526
MOV     K400        D527
MOV     K400        D528
MOV     K80         D529
MOV     K60         D530
MOV     K8          D531
MOV     K300        D532
MOV     K50         D540
MOV     K50         D541
MOV     K0          D542
MOV     K150        D543
MOV     K150        D544
MOV     K10         D545
MOV     K50         D546
MOV     K0          D554
MOV     K2          D555
MOV     K600        D603
MOV     K1400       D604
MOV     K2200       D605
SET     M508
MOV     K300        D547
DMOV    K5          D548
DMOV    K50         D550
MOV     K300        D552
DMOV    K0          D564
SET     M500
RST     M506
RST     M507
DMOV    K0          D640
ZRST    D640        D671
DMOV    K20         D672
SRET
END

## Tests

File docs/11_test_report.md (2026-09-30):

# ۱۱. گزارش تست نقطه‌به‌نقطه‌ی برنامه‌ی PLC

> این فایل را `python3 tools/test_suite.py` خودکار می‌سازد. هر سناریو برنامه‌ی واقعی `plc/TampoPrinter_SV2.il` را اسکن‌به‌اسکن (هر ۵ ms) روی مدل دستگاه اجرا می‌کند، خطا تزریق می‌کند و نتیجه را بررسی می‌کند. در هر اسکن، مدل دستگاه قانون‌های ایمنی را هم کنترل می‌کند: حرکت X با پد پایین، پد روی سطح حین حرکت، و حرکت کاپ زیر پد.

## خلاصه

| مورد | نتیجه |
|---|---|
| سناریوها | **57 از 57** قبول |
| بررسی‌ها | **298 از 298** قبول |
| دستورهای خروجی اجراشده (پوشش کد) | **641 از 652** (98٪) |
| مرحله‌های اتومات دیده‌شده | S0, S5, S10, S20, S50, S60, S70, S80, S90, S100, S110 (S5، S40 و S120 در همان اسکن تمام می‌شوند و با پوشش کد تأیید می‌شوند) |
| مرحله‌های جوهرزنی / هومینگ | D1: [0, 10, 20] · D2: [0, 10, 30, 40] · D3: [0, 15, 20, 25] |
| آلارم‌های آزموده‌شده | A01, A02, A03, A04, A05, A06, A07, A08, A09, A10, A11, A12, A13, A14, A15, A16, A17, A18, A19, A20, A21 (21 از 21) |

## سناریوها

### ✅ S01: Auto cycle, serial inking, 1 pedal = 1 print

- ✅ homing
- ✅ auto started
- ✅ 3 prints
- ✅ no alarm, no collision
- ✅ every held auto step visited

### ✅ S02: Auto cycle, parallel inking

- ✅ homing
- ✅ 3 prints
- ✅ ink sub-sequence visited
- ✅ no alarm, no collision

### ✅ S03: Early Z descent 5 mm

- ✅ homing
- ✅ 3 prints
- ✅ no alarm, no collision

### ✅ S04: Pre-pick + early Z + parallel inking

- ✅ homing
- ✅ 3 prints
- ✅ pad loaded and waiting for pedal
- ✅ pad re-picks after max wait (D552)
- ✅ no alarm, no collision

### ✅ S05: Mode 1: one pedal = N prints

- ✅ homing
- ✅ 6 prints
- ✅ 2 pedals for 6 prints
- ✅ no alarm, no collision

### ✅ S06: Mode 2: continuous

- ✅ homing
- ✅ 4 prints without pedal
- ✅ no alarm, no collision

### ✅ S07: Stop at end of cycle

- ✅ homing
- ✅ auto stops by itself
- ✅ stopped at S0, pad up
- ✅ no alarm

### ✅ S08: Batch target reached

- ✅ homing
- ✅ exactly 3 prints then stop
- ✅ batch done flag
- ✅ start refused until batch reset
- ✅ batch reset clears flag

### ✅ S09: Homing starting on the X home sensor (back-off)

- ✅ homing
- ✅ back-off step used
- ✅ no alarm

### ✅ S10: Homing: X sensor stuck ON -> A11

- ✅ A11 raised
- ✅ not homed

### ✅ S11: Homing: X sensor never seen -> A11 by timeout

- ✅ A11 raised by timeout

### ✅ S12: Manual jog X homed (soft limits, hold-to-run)

- ✅ homing
- ✅ jog+ stops at soft max 750 mm
- ✅ release stops jog-
- ✅ no alarm

### ✅ S13: Manual jog X not homed: max 50 mm per press

- ✅ moved 50 mm at most

### ✅ S14: Manual go-to and Y test stroke

- ✅ homing
- ✅ X at print
- ✅ X at pick
- ✅ Y at end
- ✅ Y at park
- ✅ Y test stroke done, image inked
- ✅ no alarm

### ✅ S15: Manual Z only at pick (cup parked) or print

- ✅ homing
- ✅ Z down at pick
- ✅ Z refused between stations
- ✅ no alarm

### ✅ S16: A01 E-stop during auto

- ✅ homing
- ✅ A01 raised
- ✅ auto aborted, motion stopped
- ✅ pad up
- ✅ no collision
- ✅ alarm clears after reset
- ✅ homing lost (class A)
- ✅ re-home
- ✅ production resumes

### ✅ S17: A02 / A03 drive faults

- ✅ homing
- ✅ A02 raised
- ✅ auto aborted, motion stopped
- ✅ pad up
- ✅ no collision
- ✅ alarm clears after reset
- ✅ homing lost (class A)
- ✅ re-home
- ✅ production resumes

### ✅ S17b: A03 Y drive fault

- ✅ homing
- ✅ A03 raised
- ✅ auto aborted, motion stopped
- ✅ pad up
- ✅ no collision
- ✅ alarm clears after reset
- ✅ homing lost (class A)
- ✅ re-home
- ✅ production resumes

### ✅ S18: A04 X over-travel

- ✅ homing
- ✅ A04 raised
- ✅ auto aborted, motion stopped
- ✅ pad up
- ✅ no collision
- ✅ alarm clears after reset
- ✅ homing lost (class A)
- ✅ re-home
- ✅ production resumes

### ✅ S18b: A05 Y over-travel

- ✅ homing
- ✅ A05 raised
- ✅ auto aborted, motion stopped
- ✅ pad up
- ✅ no collision
- ✅ alarm clears after reset
- ✅ homing lost (class A)
- ✅ re-home
- ✅ production resumes

### ✅ S19: A06 air pressure low

- ✅ homing
- ✅ A06 raised
- ✅ auto aborted, motion stopped
- ✅ pad up
- ✅ no collision
- ✅ alarm clears after reset
- ✅ production resumes

### ✅ S20: A07 Z does not come down

- ✅ homing
- ✅ A07 raised
- ✅ auto aborted, motion stopped
- ✅ pad up
- ✅ no collision
- ✅ alarm clears after reset
- ✅ production resumes

### ✅ S21: A08 Z does not go up

- ✅ homing
- ✅ A08 raised
- ✅ auto aborted, motion stopped
- ✅ pad up
- ✅ no collision
- ✅ alarm clears after reset
- ✅ production resumes

### ✅ S22: A09 Z sensors UP and DOWN together

- ✅ homing
- ✅ A09 raised
- ✅ auto aborted, motion stopped
- ✅ pad up
- ✅ no collision
- ✅ alarm clears after reset
- ✅ re-home after secondary alarm
- ✅ production resumes

### ✅ S23: A10 pad drops while X moves

- ✅ homing
- ✅ X moving
- ✅ A10 raised
- ✅ X stopped at once
- ✅ no further X travel after the fault
- ✅ recovers after reset + homing

### ✅ S24: A13 light curtain during motion

- ✅ homing
- ✅ A13 raised
- ✅ auto aborted, motion stopped
- ✅ pad up
- ✅ no collision
- ✅ alarm clears after reset
- ✅ production resumes

### ✅ S25: A14 HMI communication lost

- ✅ homing
- ✅ A14 raised
- ✅ held jog bit cleared
- ✅ X stopped
- ✅ alarm clears when comms return

### ✅ S26: A15 invalid parameter

- ✅ homing
- ✅ A15 raised
- ✅ start refused
- ✅ clears after correction

### ✅ S27: A16 step timeout (cup axis stalls)

- ✅ homing
- ✅ A16 raised
- ✅ auto aborted
- ✅ safe reset recovers

### ✅ S28: A17 pad reported down while X moves

- ✅ homing
- ✅ A17 raised
- ✅ X stopped

### ✅ S29: A18 X path through a forbidden zone

- ✅ homing
- ✅ A18 raised
- ✅ X never entered the zone
- ✅ D680 shows path blocked

### ✅ S30: A18 Y path through a forbidden zone

- ✅ homing
- ✅ A18 raised
- ✅ Y never entered the zone

### ✅ S31: Jog stops before a zone (margin 2 mm)

- ✅ homing
- ✅ stopped at 398 mm
- ✅ cannot jog further
- ✅ no alarm

### ✅ S32: No-drop zone at the print station

- ✅ homing
- ✅ A18 raised at the pad-down step
- ✅ pad never came down in the zone

### ✅ S33: A19 axis already inside a zone, then jog out

- ✅ homing
- ✅ A19 raised
- ✅ reset accepted
- ✅ jogged out of the zone

### ✅ S34: A20 PLC operation error + safe reset

- ✅ homing
- ✅ A20 raised with code/step kept
- ✅ D680 shows PLC error
- ✅ safe reset clears flag and alarm

### ✅ S35: A21 corrupted step register repaired

- ✅ homing
- ✅ A21 raised
- ✅ sequence stopped safely, pad up
- ✅ no collision
- ✅ production resumes

### ✅ S36: Software safe reset during motion

- ✅ homing
- ✅ everything stopped, pad up
- ✅ no alarm, homing kept
- ✅ restart works

### ✅ S37: Restore default parameters

- ✅ print position back to 495.0
- ✅ zones cleared

### ✅ S38: Black box records the first alarm

- ✅ homing
- ✅ one black-box entry
- ✅ entry code = A13
- ✅ entry keeps the step it happened in

### ✅ S39: Diagnostics: why won't it run (D680)

- ✅ not homed shown
- ✅ login missing shown
- ✅ homing
- ✅ not-homed bit clears
- ✅ air low shown

### ✅ S40: Operators, shifts, session log

- ✅ homing
- ✅ start refused without login
- ✅ unknown code rejected
- ✅ 1234 logged in
- ✅ 3 prints
- ✅ 1234 shift count = 3
- ✅ session record for 1234
- ✅ 2 more prints on 5678
- ✅ shift change closes 5678 session
- ✅ shift 2, counters cleared
- ✅ logout
- ✅ no alarm, no collision

### ✅ S41: Power cycle keeps parameters, comes up safe

- ✅ homing
- ✅ not homed, not running
- ✅ pad goes up
- ✅ parameter kept
- ✅ home + print after power-up

### ✅ S42: Random fuzz #1

- ✅ no collision in 160 random actions
- ✅ recovers: safe reset, home, print

### ✅ S43: Random fuzz #2

- ✅ no collision in 160 random actions
- ✅ recovers: safe reset, home, print

### ✅ S44: Random fuzz #3

- ✅ no collision in 160 random actions
- ✅ recovers: safe reset, home, print

### ✅ S45: Out-of-range parameters are clamped

- ✅ D540 5 -> 20
- ✅ D541 5 -> 20
- ✅ D522 2000 -> 900
- ✅ D527 900 -> 600
- ✅ D528 900 -> 600
- ✅ D526 10 -> 100
- ✅ D532 10 -> 100
- ✅ D552 5000 -> 1000
- ✅ D554 5 -> 0
- ✅ D555 0 -> 1
- ✅ D540 500 -> 100
- ✅ D541 500 -> 100
- ✅ D554 -1 -> 0
- ✅ D555 20 -> 9
- ✅ D500 20000 -> 7500
- ✅ D500 -50 -> 0
- ✅ D502 20000 -> 7500
- ✅ D502 -50 -> 0

### ✅ S46: Homing: Y sensor stuck ON -> A12

- ✅ A12 raised

### ✅ S47: Y jog with zones and without homing

- ✅ unhomed Y jog+ max 50 mm
- ✅ unhomed Y jog- max 50 mm
- ✅ homing
- ✅ Y jog+ stops at 198 mm
- ✅ Y jog- stops at 32 mm
- ✅ no alarm

### ✅ S48: X jog- with a zone behind, unhomed X jog-

- ✅ unhomed X jog- max 50 mm
- ✅ homing
- ✅ X jog- stops at 22 mm
- ✅ jog+ away from the zone works

### ✅ S49: Ring buffers wrap: 70 sessions, 18 black-box entries

- ✅ 70 records written
- ✅ session slot wrapped (70 mod 64 = 6)
- ✅ 18 black-box entries
- ✅ black-box slot wrapped (18 mod 16 = 2)

### ✅ S50: Login message timeout, total reset, auto start off-station

- ✅ unknown code message shown
- ✅ message clears after 3 s
- ✅ total counter reset
- ✅ homing
- ✅ start from the print station
- ✅ no alarm

### ✅ S51: Inductive Z sensors: X20 wire break / lost steel flag during auto

- ✅ homing
- ✅ A09 raised
- ✅ auto aborted, motion stopped
- ✅ pad up
- ✅ no collision
- ✅ alarm clears after reset
- ✅ re-home after secondary alarm
- ✅ production resumes

### ✅ S52: Inductive Z sensors: without X20 the X axis stays locked (fail-safe)

- ✅ homing
- ✅ A09 raised (UP without SAFE)
- ✅ X did not move
- ✅ no collision
- ✅ alarm clears after reset
- ✅ X moves again with a healthy sensor

### ✅ S53: X axis jammed: stop, driver limp, back off 5 mm on reset

- ✅ homing
- ✅ jam detected while moving (A02/A03)
- ✅ pulses stopped at once
- ✅ stall and direction remembered
- ✅ backed off 5 mm the other way
- ✅ back-off done once, flags cleared
- ✅ axis unhomed (position not trusted)
- ✅ no new alarm, no collision
- ✅ re-home works

### ✅ S54: Cup axis (Y) jammed: stop, back off 5 mm on reset

- ✅ homing
- ✅ jam detected while moving (A02/A03)
- ✅ pulses stopped at once
- ✅ stall and direction remembered
- ✅ backed off 5 mm the other way
- ✅ back-off done once, flags cleared
- ✅ axis unhomed (position not trusted)
- ✅ no new alarm, no collision
- ✅ re-home works

### ✅ S55: X jammed on the way back (-): backs off in + direction

- ✅ homing
- ✅ jam detected, direction = -
- ✅ backed off 5 mm in + direction
- ✅ no alarm, no collision

## خط‌های اجرانشده

دستورهای خروجی که در هیچ سناریویی اجرا نشدند (شماره‌ی خط در فایل IL):

```
  120  DMOV    K200        D690
  122  DMOV    K0          D690
  124  DMOV    K200        D692
  126  DMOV    K0          D692
  247  SET     M211
  966  MOV     K10         D0
 1626  DMOV    D30         D200
 1647  DMOV    D30         D200
 1696  SET     M65
 1720  DMOV    D34         D204
 1741  DMOV    D34         D204
```

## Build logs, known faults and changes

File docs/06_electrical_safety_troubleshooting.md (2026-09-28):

# ۶. برق، ضد نویز، گراندینگ، مدار ایمنی و عیب‌یابی

## ۶-۱ معماری تغذیه

```
 230VAC ──[MCB 10A]──[Main Switch]──┬──[Filter EMI]──┬── PSU 48V/10A (یا 36V) ──[Fuse 10A]──┬─ CL57-X
                                    │                │        │                            └─ CL57-Y
                                    │                │   [KM1 DC contactor, کنتاکت تأخیری رله‌ی ایمنی]
                                    │                │
                                    │                └── PSU 24V/5A ─┬─[F1 2A]── PLC + HMI + رله‌ی ایمنی
                                    │                                ├─[F2 2A]── سنسورها
                                    │                                └─[F3 3A]── شیرها و چراغ‌ها (خروجی‌ها)
                                    └── PE ─────────────── شینه‌ی ارت تابلو (ستاره‌ای)
```

* **جداسازی مدارها:** 24V شیرها و بارهای سلفی را با فیوز جدا از 24V منطقی PLC و سنسورها تغذیه کنید. ایده‌آل این است که یک پاور 24V کوچک جداگانه داشته باشند.
* **0V پاورها:** 0V منبع 24V را در **یک نقطه** به PE وصل کنید (PELV). 0V منبع 48V را **به PE وصل نکنید**، مگر اینکه دفترچه‌ی CL57 خواسته باشد. این کار از حلقه‌ی زمین (Ground Loop) در مسیر برگشت جریان موتور جلوگیری می‌کند.
* **پاور 48V:** اگر 48V می‌ماند، یک **خازن ≥ 4700 µF / 100V** در ورودی هر درایور بگذارید، یا **دیود سری و Regen Clamp**. جزئیات در بخش ۱-۶ آمده است.

## ۶-۲ سیم‌بندی درایور CL57 و PLC

```
 PLC SV2 (NPN, sink)                     CL57
 ─────────────────                      ──────
 +24V ─────────────────────[R*]──────── PUL+
 Y0 ───────────────────────────────────  PUL−
 +24V ─────────────────────[R*]──────── DIR+
 Y1 ───────────────────────────────────  DIR−
 C0 (کامن Y0..Y3) ─────── 0V

 +24V ── KA6 (NC contact) ───────────── ENA+       ← Y6 رله‌ی KA6 را روشن می‌کند
 0V  ──────────────────────────────────  ENA−         (Y6=ON ⇒ NC باز ⇒ ENA بی‌جریان ⇒ درایور فعال)

 ALM+ ── +24V ;  ALM− ──────────────── X4  (با تنظیم سطح فعال ALM در ProTuner به «هدایت در حالت سالم»)
```

* **R\*:** اگر ورودی CL57 شما فقط 5V است، برای 24V مقاومت **2.2 کیلواهم ۰.۵ وات** سری بگذارید. نسخه‌های جدیدتر 24V را مستقیم می‌پذیرند (دفترچه را ببینید).
* **قطبیت ENA:** در بیشتر درایورهای Leadshine، **جریان در ENA یعنی درایور غیرفعال**. سیم‌بندی بالا طوری است که قطع برق PLC، قطع کابل یا Y6 = OFF، درایور را **غیرفعال** کند. (اگر درایور شما برعکس است، از کنتاکت NO استفاده کنید.)
* **ALM:** سیم‌بندی را طوری انجام دهید که **قطع سیم هم آلارم** دیده شود، یعنی در حالت سالم X4 = 1.
* **سیم Y0 تا Y3 تا درایور:** کابل زوج به‌هم‌تابیده‌ی شیلددار (PUL و DIR هر کدام یک زوج). **حداکثر حدود ۳ متر**. شیلد فقط **سمت PLC** به PE.
* **DIR setup time:** DDRVA قبل از پالس، DIR را تنظیم می‌کند. CL57 دست‌کم حدود ۵ µs فاصله لازم دارد که SV2 به‌طور ذاتی رعایت می‌کند.

## ۶-۳ ضد نویز و گراندینگ

| # | اقدام | دلیل |
|---|---|---|
| 1 | **کابل موتور شیلددار ۴ رشته** (2×2×0.75)، شیلد **۳۶۰ درجه** با کلمپ EMC به صفحه‌ی تابلو در سمت درایور | کابل موتور بزرگ‌ترین منبع نویز PWM است |
| 2 | **کابل انکودر** (کلوزلوپ) شیلددار، **جدا** از کابل موتور. هر دو در زنجیر کابلی (Drag Chain) با **فاصله‌ی دست‌کم ۵۰ mm** یا با جداکننده | اگر نویز به انکودر برسد، CL57 آلارم Position Error می‌دهد. **شایع‌ترین فالت این ماشین‌هاست** |
| 3 | در تابلو **سه داکت جدا**: قدرت (230V و 48V موتور)، سیگنال DC (پالس و سنسور)، و RS-485. تقاطع‌ها با زاویه‌ی ۹۰ درجه | |
| 4 | **دیود هرزگرد** (1N4007) یا **TVS** موازی بوبین شیرها و رله‌های KA6 و KA7. برای شیرهای SMC نسخه‌ی با LED و Surge Suppressor سفارش دهید | ولتاژ القایی لحظه‌ی قطع بوبین از ۳۰۰ ولت بیشتر می‌شود و روی ورودی‌ها نویز می‌اندازد |
| 5 | **فیلتر EMI تک‌فاز** ورودی 230V، نزدیک ورودی تابلو | |
| 6 | **فریت** روی کابل RS-485 و کابل ۴۸V هر درایور | |
| 7 | **شینه‌ی ارت ستاره‌ای**. بدنه‌ی موتورها، شاسی ماشین، درب تابلو (با بافته‌ی مسی) و PE ورودی همه به یک نقطه | |
| 8 | سنسورهای القایی: کابل **جدا از کابل موتور** در Drag Chain. در صورت نیاز، ورودی‌های X0 و X1 را با فیلتر نرم‌افزاری (`D1020`) کمی کند کنید | |
| 9 | صفحه‌ی نصب تابلو **گالوانیزه** (نه رنگی) برای اتصال فلز به فلز کلمپ‌های EMC | |
| 10 | RS-485: ترمیناتور ۱۲۰ اهم، **شیلد و 0V SG** وصل شوند. طول بیشتر از ۱۰ متر نیاز به ایزولاتور دارد | |

## ۶-۴ مدار ایمنی (E-Stop و Guard)

```
                    ┌─────────────── Safety Relay (e.g. PNOZ s4 + s7.1 time-delayed) ───────────────┐
 E-Stop (2-ch NC) ──┤ S11-S12 / S21-S22                                                            │
 Light curtain OSSD ┤ (یا ماژول دوم)                                                                │
 Reset (NO)      ───┤ S33-S34                                                                      │
                    │  13-14  instant  ──── +24V → SOL-A (Y4 Z-DOWN coil feed)                     │
                    │  23-24  instant  ──── KA6 / KA7 coil feed (ENA X/Y)                          │
                    │  37-38  delayed 0.5–1 s ─── KM1 (48V drive power, Stop Cat. 1)                │
                    │  Aux NC/NO ────── X10 (ESTOP_OK)  / X16 (GUARD_OK)                            │
                    └──────────────────────────────────────────────────────────────────────────────┘
```

**ترتیب اتفاق‌ها در E-Stop:**

1. **t = 0:** رله‌ی ایمنی تغذیه‌ی بوبین Down را قطع می‌کند. PLC از طریق X10 خبردار می‌شود، Y5 (Up) روشن می‌ماند و **پد بالا می‌رود**.
2. **t = 0:** PLC با `M1078` و `M1104` پالس‌ها را فوراً قطع می‌کند و Y6 و Y7 را OFF می‌کند. کنتاکت 23-24 هم ENA را قطع می‌کند.
3. **t = 0.5 تا 1 s:** برق 48V درایورها با KM1 قطع می‌شود (Stop Category 1).
4. **هوای اصلی تخلیه نمی‌شود،** تا پد نیفتد. شیر پایلوت‌چک روی جک هم در صورت قطع هوا پد را بالا نگه می‌دارد.
5. پس از رفع E-Stop: اول Reset رله‌ی ایمنی، بعد Reset روی PLC، بعد **هومینگ**.

**پرده‌ی نوری:** نوع ۲ برای PL c یا نوع ۴ برای PL d/e، با **فاصله‌ی ایمنی** طبق ISO 13855: `S = K × T + C`، با K = 2000 mm/s. T یعنی زمان کل توقف پد، که با **تست زمان توقف** اندازه‌گیری می‌شود.

## ۶-۵ جدول آلارم‌ها و روتین عیب‌یابی

| کد | بیت | پیام | علت‌های محتمل | اقدام |
|---|---|---|---|---|
| **A01** | M200 | توقف اضطراری | شستی فشرده شده، رله‌ی ایمنی Reset نشده، پرده‌ی نوری یا مدار ایمنی باز است | شستی را آزاد کنید، Reset رله‌ی ایمنی، Reset روی PLC، هوم |
| **A02** | M201 | فالت درایور X **یا گیر کردن محور** | ① Position following error (نویز انکودر، بار سنگین، شتاب زیاد، تسمه‌ی شل یا گیر مکانیکی) ② Over-voltage (برق برگشتی) ③ Over-current یا اتصال کوتاه کابل موتور ④ قطع کابل ALM | **روال پایین را ببینید** |
| **A03** | M202 | فالت درایور Y | همانند A02. بعلاوه: اصطکاک زیاد کاپ (رینگ خشک، رنگ غلیظ یا آهنربای قوی) | |
| **A04** | M203 | Over-travel X | عبور از لیمیت سخت‌افزاری، اشتباه پارامتر Soft-Limit، از دست رفتن گام در حالت هوم‌نشده | با دست کالسکه را از روی لیمیت کنار بکشید (درایور غیرفعال است). Reset. هوم |
| **A05** | M204 | Over-travel Y | همانند A04 | |
| **A06** | M205 | فشار هوا کم | کمپرسور، شیر اصلی، تنظیم پرشر سوئیچ (معمولاً حدود ۴.۵ بار) | |
| **A07** | M206 | Z به پایین نرسید | فلوکنترل خیلی بسته، سنسور Down جابه‌جا شده، اختلاف ارتفاع قطعه، قطعه یا فیکسچر مانع است، فشار کم | ارتفاع سنسور و تنظیم فلوکنترل را چک کنید. Timeout را بالا ببرید |
| **A08** | M207 | Z بالا نرفت | پد به کلیشه چسبیده (مکش)، فلوکنترل بسته، سنسور Up جابه‌جا شده، بوبین B سوخته | |
| **A09** | M208 | خطای سنسورهای Z | Up و Down هم‌زمان، Safe و Down هم‌زمان، یا **Up روشن ولی Safe خاموش** (سیم X20 قطع، سنسور شل، یا تسمه‌ی آهنی افتاده) | چراغ هر سه سنسور القایی را با بالا و پایین بردن دستی پد ببینید؛ فاصله‌ی سر سنسور تا تسمه‌ی آهنی ۱.۵ تا ۲.۵ mm باشد |
| **A10** | M209 | پد حین حرکت X یا Y زیر ارتفاع امن رفت | `D550` (فرود زودهنگام) زیاد است، افت فشار، سنسور X20 جابه‌جا شده | `D550` را کم کنید. سنسورها را بررسی کنید. خطر برخورد وجود داشته است |
| **A11** | M210 | خطای هوم X | سنسور هوم قطع است یا گیر کرده (بعد از عقب‌نشینی هنوز فعال است)، فاصله‌ی سنسور تا هدف بیشتر از حدود ۴ mm است، جهت DZRN اشتباه است | LED سنسور را با دست چک کنید. جهت را چک کنید (بخش ۴-۷) |
| **A12** | M211 | خطای هوم Y | همانند A11 | |
| **A13** | M212 | گارد یا پرده‌ی نوری | ورود دست حین حرکت | |
| **A14** | M213 | قطع ارتباط HMI | کابل، ترمیناتور، Baud یا Macro مربوط به Heartbeat | صفحه‌ی ۸: آیا D60 تغییر می‌کند؟ |
| **A15** | M214 | پارامتر نامعتبر | Pick، Print یا Ready بزرگ‌تر از Soft-Max. Zone Min بزرگ‌تر از Max. Park بزرگ‌تر یا مساوی End. مقیاس صفر | صفحه‌ی ۳ |
| **A17** | M216 | پد روی قطعه یا کلیشه نشست ولی X هنوز حرکت داشت | `D550` خیلی زیاد، شتاب ترمز X کم (`D526` زیاد)، سرعت فرود Z زیاد | `D550` را کم کنید. بعد از رفع، **هومینگ** |
| **A16** | M215 | Timeout مرحله‌ی سکانس | حرکت نیمه‌کاره متوقف شده (محور به پنجره‌ی Tolerance نرسیده)، مجوز برقرار نشده | `D0` را روی صفحه‌ی ۸ ببینید و شرط‌های همان مرحله را در بخش ۳-۴ دنبال کنید |

### روال عیب‌یابی فالت درایور (A02 و A03)

```
 ┌─ 1. تعداد چشمک LED قرمز CL57 را بشمارید (کدها را با دفترچه‌ی مدل خود تطبیق دهید)
 │     • Over-current    → کابل موتور (اتصال فاز به فاز یا فاز به بدنه)، موتور را با مگر تست کنید
 │     • Over-voltage    → برق برگشتی در ترمز: شتاب کمتر، 36V، خازن یا Clamp
 │     • Position error  → برو به 2
 │
 ├─ 2. Position following error
 │     a) درایور را غیرفعال کنید و محور را با دست حرکت دهید: روان است؟  (خیر ⇒ ریل، تسمه یا گیر مکانیکی)
 │     b) تسمه: کشش (فرکانس ارتعاش) و دندانه‌های پریده
 │     c) کابل انکودر: شیلد، کانکتور، فاصله از کابل موتور  (بعد از تعویض Drag Chain شایع است)
 │     d) شتاب (D526) را ۲ برابر کنید. اگر رفع شد، اینرسی یا گشتاور مرز است ⇒ گیربکس ۱:۳ یا تنظیم گین
 │     e) ProTuner: خطای پیک در سرعت کاری را ثبت کنید
 │
 ├─ 3. رفع علت، سپس [RESET] (پالس ENA ۳۰۰ ms). اگر آلارم برقرار ماند، برق 48V را قطع و وصل کنید
 │     اگر آلارم وسط حرکت آمده بود (گیر کردن)، همین RESET محور را خودکار و آهسته D690 / D692
 │     (پیش‌فرض 5 mm) در جهت مخالف برمی‌گرداند. بعد مانع را بردارید و دوباره هوم کنید
 │
 └─ 4. هومینگ (موقعیت معتبر نیست) ⇒ یک سیکل Dry-Run ⇒ تولید
```

### عیب‌یابی علامت‌محور (کیفیت چاپ و رفتار ماشین)

| علامت | علت محتمل مکانیکی یا کنترلی |
|---|---|
| تصویر سایه‌دار یا دوبل | لرزش X در انتهای حرکت (Settling). Z را بعد از **M25 و نشست** پایین بیاورید (`D545` را افزایش دهید). ریل X در لحظه‌ی چاپ خم می‌شود |
| تصویر کم‌رنگ | Dwell1 کوتاه، فشار کم (MGPM25)، Flash-off نامناسب، ویسکوزیته |
| تکرارپذیری موقعیت ضعیف | تسمه‌ی شل، لقی پولی (Set-Screw بدون جای تخت)، سرعت Creep هوم زیاد |
| نشتی رنگ از کاپ | کوپل صلب کاپ، شتاب زیاد Y، سایش رینگ، آهنربا ضعیف |
| محور گاهی بی‌دلیل می‌ایستد | نویز روی ورودی لیمیت (X6 و X7): کابل جدا کنید، فیلتر ورودی بگذارید |

## ۶-۶ نگهداری دوره‌ای

| دوره | کار |
|---|---|
| روزانه | تمیزی کلیشه و پد، سطح رنگ، فشار هوا، تست E-Stop |
| هفتگی | کشش تسمه‌ها، گریس ریل‌ها (HGR15 و ریل X)، تخلیه‌ی آب فیلتر هوا |
| ماهانه | پیچ سنسورهای D-M9N و سنسورهای هوم، کلمپ‌های شیلد، دمای درایورها |
| ۶ ماهه | تست زمان توقف پرده‌ی نوری، سایش رینگ کاپ، شاک‌آبزوربر |

## حفاظت محورهای X و کاپ در برابر گیر کردن (نسخه‌ی ۲.۳)

**هدف:** اگر چیزی سر راه ریل یا کاپ گیر کند، دستگاه با نیرویی **کمی بیشتر از نیروی عادی** (مثلاً ۴۰٪) متوقف شود، نه با تمام زور موتور، و کمی به عقب برگردد.

**چرا با استپر عدد نیرو را مستقیم نمی‌خوانیم؟** درایور استپر همیشه تا سقف جریانی که روی آن تنظیم شده به موتور جریان می‌دهد و عددی از نیرو به PLC نمی‌فرستد. ولی **زور موتور متناسب با همین سقف جریان است**. پس اگر سقف جریان را درست تنظیم کنیم، موتور **فیزیکی** نمی‌تواند بیشتر از آن حد زور بزند. وقتی بار از آن بیشتر شود، موتور عقب می‌ماند، درایور کلوزلوپ آلارم می‌دهد و:

1. PLC پالس را فوراً قطع می‌کند (A02 برای X، A03 برای کاپ).
2. درایور جریان موتور را قطع می‌کند، موتور شل می‌شود و **دیگر هیچ فشاری نمی‌آورد**.
3. PLC محور و جهت حرکت را ثبت می‌کند (M180/M181 و M182/M183).
4. با زدن **RESET**، محور آهسته **۵ mm** (قابل تنظیم با D690 / D692) در جهت مخالف برمی‌گردد تا فشار از روی قطعه‌ها برداشته شود.
5. محور «هوم‌نشده» می‌ماند. مانع را بردارید و هومینگ بزنید.

### تنظیم «۴۰٪ بیشتر» بعد از نصب (هر محور جدا)

**گام ۱: نیروی لازم را اندازه بگیرید (اختیاری ولی مفید)**
* درایور را خاموش کنید (E-Stop). یک **نیروسنج دستی** (Push-Pull Gauge یا ترازوی فنری) به کالسکه ببندید و آهسته در طول کل مسیر بکشید.
* عدد بیشترین نیرو را یادداشت کنید. این **نیروی اصطکاک** است (معمولاً چند ده نیوتن).
* نیروی شتاب هم اضافه می‌شود: جرم × شتاب. برای X حدود ۲۲ kg × ۲.۸ m/s² ≈ ۶۰ N.
* اگر سال بعد اصطکاک خیلی بیشتر شد، یعنی ریل کثیف است یا تسمه بیش از حد سفت شده.

**گام ۲: کمترین جریانی را که دستگاه با آن درست کار می‌کند پیدا کنید**
1. همه‌چیز نصب و روغن‌کاری شده باشد. تسمه با کشش درست بسته شده باشد.
2. جریان درایور را روی مقدار نامی موتور بگذارید (DIP سوئیچ یا نرم‌افزار درایور).
3. با **سرعت و شتاب تولید**، در حالت خشک (`M503 = 1`) حدود ۲۰ سیکل کامل بزنید.
4. جریان را **یک پله** پایین بیاورید و دوباره ۲۰ سیکل بزنید.
5. آن‌قدر ادامه دهید تا A02 (یا A03) بیاید. **آخرین پله‌ای که بدون آلارم کار کرد** را یادداشت کنید (I_min).

**گام ۳: جریان را روی ۱.۴ × I_min بگذارید**
* زور موتور تقریباً متناسب با جریان است، پس دستگاه حداکثر با **حدود ۴۰٪ بیشتر از نیروی لازم** فشار می‌آورد و بعد آلارم می‌دهد.
* اگر در روزهای سرد یا بعد از چند روز کار آلارم بی‌دلیل آمد، ۱.۵ برابر بگذارید.
* عدد جریان را روی برچسب کنار درایور بنویسید. هر ۳ ماه یک بار گام ۲ را تکرار کنید.

**گام ۴ (اختیاری): حد خطای موقعیت درایور**
* در نرم‌افزار تنظیم درایور کلوزلوپ، «حد خطای موقعیت» (Position Error Limit) را تا جایی که آلارم بی‌دلیل نمی‌آید کم کنید تا درایور زودتر گیر کردن را بفهمد.
* نام و بازه‌ی این پارامتر را با دفترچه‌ی مدل درایور خودتان تطبیق دهید.

> این حفاظت برای **سالم ماندن دستگاه** است، نه دست اپراتور. برای دست، فرود با فشار کم یا اسکنر ایمنی لازم است (بخش ۱۳-۸).
>
> **تست:** سناریوهای S53 تا S55 در [گزارش تست](11_test_report.md): گیر کردن X در هر دو جهت و گیر کردن کاپ، توقف فوری، برگشت ۵ mm، و هومینگ دوباره.

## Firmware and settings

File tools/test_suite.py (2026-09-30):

#!/usr/bin/env python3
"""Point-by-point test suite for plc/TampoPrinter_SV2.il.

Every scenario runs the real IL program in tools/plc_sim.py against the
machine model, injects faults where needed and checks the outcome. The
suite measures which sequence steps, alarms and output instructions were
exercised and writes docs/11_test_report.md.

    python3 tools/test_suite.py            # all scenarios, 4 processes
    python3 tools/test_suite.py S16 S29    # selected scenarios
"""
import os
import random
import sys
import traceback
from multiprocessing import Pool

sys.path.insert(0, os.path.dirname(__file__))
import plc_sim                                       # noqa: E402
from plc_sim import SCAN, Sim                        # noqa: E402

ALARMS = {200 + i: "A%02d" % (i + 1) for i in range(21)}
AUTO_STEPS = [0, 5, 10, 20, 40, 50, 60, 70, 80, 90, 100, 110, 120]
# S5, S40 (flash-off 0) and S120 finish inside the scan that enters them,
# so they never show at the end of a scan; code coverage proves them.
AUTO_STEPS_HELD = [0, 10, 20, 50, 60, 70, 80, 90, 100, 110]
INK_STEPS = [0, 10, 20]
HOME_STEPS = [0, 10, 20, 30, 40]
AXIS_HOME_STEPS = [0, 10, 15, 20, 25]


# ------------------------------------------------------------------ harness
class TSim(Sim):
    def __init__(self, login=False):
        super().__init__()
        self.steps = {k: set() for k in ("D0", "D1", "D2", "D3", "D4")}
        self.alarms_seen = set()
        self.hook = None
        self.pedals = 0
        self.run(0.1)
        if not login:
            self.plc.bits["M508"] = False

    def run(self, seconds, until=None):
        p = self.plc
        for _ in range(int(round(seconds / SCAN))):
            self.plant.inputs()
            p.scan()
            p.pulse_step(self.plant)
            self.plant.step()
            w = p.words
            for k, st in self.steps.items():
                st.add(w[k])
            for i in range(200, 221):
                if p.bits["M%d" % i]:
                    self.alarms_seen.add(i)
            if self.hook:
                self.hook(self)
            if until and until():
                return True
        return False

    # helpers
    def b(self, n):
        return self.plc.bits[n]

    def alarms(self):
        return [ALARMS[i] for i in range(200, 221) if self.plc.bits["M%d" % i]]

    def home(self):
        self.cmd("M103")
        ok = self.run(40, until=lambda: self.b("M24") and self.w("D2") == 0)
        self.run(0.1)
        return ok

    def reset(self):
        self.cmd("M102")
        self.run(0.5)

    def start_auto(self, mode=0, n=None):
        self.plc.put("D554", mode)
        if n is not None:
            self.plc.put("D555", n)
        self.plc.bits["M120"] = True
        self.cmd("M100")
        self.run(0.3)
        return self.b("M90")

    def prints(self, n, timeout=90, pedal=True):
        start = self.w("D560", True)
        t_end = self.plant.t + timeout
        while self.w("D560", True) - start < n and self.plant.t < t_end:
            if pedal and self.w("D0") == 10 and not self.b("M94") \
                    and self.plant.t > self.plant.pedal_until + 0.2:
                self.pedal()
                self.pedals += 1
            if self.b("M21"):
                break
            self.run(0.05)
        return self.w("D560", True) - start

    def xpos(self):            # PLC frame, mm
        return self.w("D1030", True) / 100.0

    def ypos(self):
        return self.w("D1336", True) / 33.333

    def set_zone(self, base, k, lo_mm, hi_mm):
        self.plc.put("D%d" % (base + 4 * k), int(lo_mm * 10), True)
        self.plc.put("D%d" % (base + 4 * k + 2), int(hi_mm * 10), True)


def ck(checks, desc, ok):
    checks.append((desc, bool(ok)))


def clean(s):
    return not s.alarms() and not s.plant.violations


# ------------------------------------------------------------------ scenarios
def S01(s, c):
    """Auto cycle, serial inking, 1 pedal = 1 print"""
    s.plc.bits["M500"] = False
    ck(c, "homing", s.home())
    ck(c, "auto started", s.start_auto(0))
    ck(c, "3 prints", s.prints(3) == 3)
    ck(c, "no alarm, no collision", clean(s))
    ck(c, "every held auto step visited", set(AUTO_STEPS_HELD) <= s.steps["D0"])


def S02(s, c):
    """Auto cycle, parallel inking"""
    ck(c, "homing", s.home())
    s.start_auto(0)
    ck(c, "3 prints", s.prints(3) == 3)
    ck(c, "ink sub-sequence visited", {10, 20} <= s.steps["D1"])
    ck(c, "no alarm, no collision", clean(s))


def S03(s, c):
    """Early Z descent 5 mm"""
    s.plc.bits["M507"] = True
    ck(c, "homing", s.home())
    s.start_auto(0)
    ck(c, "3 prints", s.prints(3) == 3)
    ck(c, "no alarm, no collision", clean(s))


def S04(s, c):
    """Pre-pick + early Z + parallel inking"""
    s.plc.bits["M506"] = True
    s.plc.bits["M507"] = True
    ck(c, "homing", s.home())
    s.start_auto(0)
    ck(c, "3 prints", s.prints(3) == 3)
    s.run(6, until=lambda: s.b("M93") and s.w("D0") == 10)
    ck(c, "pad loaded and waiting for pedal", s.b("M93") and s.w("D0") == 10)
    s.run(3.5)
    ck(c, "pad re-picks after max wait (D552)", s.steps["D0"] >= {10, 20})
    ck(c, "no alarm, no collision", clean(s))


def S05(s, c):
    """Mode 1: one pedal = N prints"""
    ck(c, "homing", s.home())
    s.start_auto(1, n=3)
    ck(c, "6 prints", s.prints(6) == 6)
    ck(c, "2 pedals for 6 prints", s.pedals == 2)
    ck(c, "no alarm, no collision", clean(s))


def S06(s, c):
    """Mode 2: continuous"""
    ck(c, "homing", s.home())
    s.start_auto(2)
    ck(c, "4 prints without pedal", s.prints(4, pedal=False) == 4)
    ck(c, "no alarm, no collision", clean(s))


def S07(s, c):
    """Stop at end of cycle"""
    ck(c, "homing", s.home())
    s.start_auto(2)
    s.run(1.0)
    s.cmd("M101")
    done = s.run(15, until=lambda: not s.b("M90"))
    ck(c, "auto stops by itself", done)
    s.run(1.5)
    ck(c, "stopped at S0, pad up", s.w("D0") == 0 and s.plant.z < 2)
    ck(c, "no alarm", clean(s))


def S08(s, c):
    """Batch target reached"""
    s.plc.bits["M504"] = True
    s.plc.put("D564", 3, True)
    s.plc.put("D562", 0, True)
    ck(c, "homing", s.home())
    s.start_auto(2)
    s.run(40, until=lambda: not s.b("M90"))
    ck(c, "exactly 3 prints then stop", s.w("D562", True) == 3 and not s.b("M90"))
    ck(c, "batch done flag", s.b("M95"))
    ck(c, "start refused until batch reset", not s.start_auto(2))
    s.cmd("M116")
    s.run(0.2)
    ck(c, "batch reset clears flag", not s.b("M95") and s.w("D562", True) == 0)


def S09(s, c):
    """Homing starting on the X home sensor (back-off)"""
    s.plant.off["Y0"] = 0.0          # carriage sits on the DOG
    ck(c, "homing", s.home())
    ck(c, "back-off step used", 15 in s.steps["D3"])
    ck(c, "no alarm", clean(s))


def S10(s, c):
    """Homing: X sensor stuck ON -> A11"""
    s.plant.force = {"X0": True}
    s.cmd("M103")
    s.run(10, until=lambda: s.b("M210"))
    ck(c, "A11 raised", s.b("M210"))
    ck(c, "not homed", not s.b("M24"))


def S11(s, c):
    """Homing: X sensor never seen -> A11 by timeout"""
    s.plant.force = {"X0": False}
    s.cmd("M103")
    s.run(35, until=lambda: s.b("M210"))
    ck(c, "A11 raised by timeout", s.b("M210"))


def S12(s, c):
    """Manual jog X homed (soft limits, hold-to-run)"""
    ck(c, "homing", s.home())
    s.plc.bits["M104"] = True
    s.run(12)
    s.plc.bits["M104"] = False
    s.run(0.3)
    ck(c, "jog+ stops at soft max 750 mm", abs(s.xpos() - 750) < 1)
    s.plc.bits["M105"] = True
    s.run(1.0)
    s.plc.bits["M105"] = False
    s.run(0.3)
    x = s.xpos()
    ck(c, "release stops jog-", 0 < x < 750 and not s.b("M1336"))
    ck(c, "no alarm", clean(s))


def S13(s, c):
    """Manual jog X not homed: max 50 mm per press"""
    s.run(2)                          # pad goes up
    x0 = s.xpos()
    s.plc.bits["M104"] = True
    s.run(10)
    s.plc.bits["M104"] = False
    s.run(0.2)
    ck(c, "moved 50 mm at most", 45 <= s.xpos() - x0 <= 50.5)


def S14(s, c):
    """Manual go-to and Y test stroke"""
    ck(c, "homing", s.home())
    s.cmd("M111")
    s.run(6)
    ck(c, "X at print", abs(s.xpos() - 495) < 0.6)
    s.cmd("M110")
    s.run(6)
    ck(c, "X at pick", abs(s.xpos() - 50) < 0.6)
    s.cmd("M113")
    s.run(6)
    ck(c, "Y at end", abs(s.ypos() - 350) < 0.6)
    s.cmd("M112")
    s.run(6)
    ck(c, "Y at park", abs(s.ypos() - 5) < 0.6)
    s.cmd("M117")
    s.run(4)
    ck(c, "Y test stroke done, image inked", s.b("M92") and s.w("D1") == 0)
    ck(c, "no alarm", clean(s))


def S15(s, c):
    """Manual Z only at pick (cup parked) or print"""
    ck(c, "homing", s.home())
    s.cmd("M108")
    s.run(1)
    ck(c, "Z down at pick", s.plant.z > 90)
    s.cmd("M109")
    s.run(1)
    s.plc.bits["M104"] = True
    s.run(0.5)
    s.plc.bits["M104"] = False
    s.run(0.3)
    s.cmd("M108")
    s.run(1)
    ck(c, "Z refused between stations", s.plant.z < 2 and not s.b("Y4"))
    ck(c, "no alarm", clean(s))


def fault_during_auto(s, c, name, apply, bit, restore, rehome):
    ck(c, "homing", s.home())
    s.start_auto(2)
    s.run(2.0)
    apply(s)
    s.run(3)
    ck(c, "%s raised" % name, s.b(bit))
    ck(c, "auto aborted, motion stopped", not s.b("M90") and not s.b("M1336") and not s.b("M1337"))
    ck(c, "pad up", s.plant.z < 2 or name in ("A07", "A08"))
    ck(c, "no collision", not s.plant.violations)
    restore(s)
    s.run(2)
    s.reset()
    ck(c, "alarm clears after reset", not s.alarms())
    if rehome:
        ck(c, "homing lost (class A)", not s.b("M24"))
        ck(c, "re-home", s.home())
    elif not s.b("M24"):              # a secondary class-A alarm fired too
        ck(c, "re-home after secondary alarm", s.home())
    ck(c, "production resumes", s.start_auto(2) and s.prints(2, pedal=False) == 2)


def _force(**kv):
    return lambda s: setattr(s.plant, "force", dict(kv))


def _clear(s):
    s.plant.force = {}
    s.plant.z_stuck = False
    s.plant.fault_down = False
    s.plant.hb_stop = False
    s.plc.stall = set()


def S16(s, c):
    """A01 E-stop during auto"""
    fault_during_auto(s, c, "A01", _force(X10=False), "M200", _clear, True)


def S17(s, c):
    """A02 / A03 drive faults"""
    fault_during_auto(s, c, "A02", _force(X4=False), "M201", _clear, True)


def S17b(s, c):
    """A03 Y drive fault"""
    fault_during_auto(s, c, "A03", _force(X5=False), "M202", _clear, True)


def S18(s, c):
    """A04 X over-travel"""
    fault_during_auto(s, c, "A04", _force(X6=False), "M203", _clear, True)


def S18b(s, c):
    """A05 Y over-travel"""
    fault_during_auto(s, c, "A05", _force(X7=False), "M204", _clear, True)


def S19(s, c):
    """A06 air pressure low"""
    fault_during_auto(s, c, "A06", _force(X15=False), "M205", _clear, False)


def S20(s, c):
    """A07 Z does not come down"""
    def apply(s):
        s.plant.z_stuck = True
    fault_during_auto(s, c, "A07", apply, "M206", _clear, False)


def S21(s, c):
    """A08 Z does not go up"""
    def apply(s):
        s.run(10, until=lambda: s.b("Y4"))
        s.run(0.4)
        s.plant.z_stuck = True
    fault_during_auto(s, c, "A08", apply, "M207", _clear, False)


def S22(s, c):
    """A09 Z sensors UP and DOWN together"""
    fault_during_auto(s, c, "A09", _force(X2=True, X3=True), "M208", _clear, False)


def S23(s, c):
    """A10 pad drops while X moves"""
    ck(c, "homing", s.home())
    s.cmd("M111")
    s.run(0.3)
    ck(c, "X moving", s.b("M1336"))
    s.plant.fault_down = True
    s.run(0.5)
    ck(c, "A10 raised", s.b("M209"))
    ck(c, "X stopped at once", not s.b("M1336"))
    xs = []
    s.hook = lambda t: xs.append(t.xpos())
    s.run(0.2)
    s.hook = None
    ck(c, "no further X travel after the fault", max(xs) - min(xs) < 0.05)
    s.plant.violations = []          # the injected fault itself, checked above
    _clear(s)
    s.run(1)
    s.reset()
    ck(c, "recovers after reset + homing", not s.alarms() and s.home())


def S24(s, c):
    """A13 light curtain during motion"""
    fault_during_auto(s, c, "A13", _force(X16=False), "M212", _clear, False)


def S25(s, c):
    """A14 HMI communication lost"""
    ck(c, "homing", s.home())
    s.plc.bits["M104"] = True               # operator holding jog
    s.run(0.3)
    s.plant.hb_stop = True
    s.run(3)
    ck(c, "A14 raised", s.b("M213"))
    ck(c, "held jog bit cleared", not s.b("M104"))
    ck(c, "X stopped", not s.b("M1336"))
    s.plant.hb_stop = False
    s.run(1)
    s.reset()
    ck(c, "alarm clears when comms return", not s.alarms())


def S26(s, c):
    """A15 invalid parameter"""
    ck(c, "homing", s.home())
    s.plc.put("D604", 500)                  # shift 2 before shift 1
    s.run(0.2)
    ck(c, "A15 raised", s.b("M214"))
    ck(c, "start refused", not s.start_auto(0))
    s.plc.put("D604", 1400)
    s.reset()
    ck(c, "clears after correction", not s.alarms())


def S27(s, c):
    """A16 step timeout (cup axis stalls)"""
    ck(c, "homing", s.home())
    s.plc.stall = {"Y2"}
    s.start_auto(2)
    s.run(20, until=lambda: s.b("M215"))
    ck(c, "A16 raised", s.b("M215"))
    ck(c, "auto aborted", not s.b("M90"))
    _clear(s)
    s.cmd("M141")                           # software safe reset
    s.run(1)
    ck(c, "safe reset recovers", not s.alarms() and s.start_auto(2) and s.prints(1, pedal=False) == 1)


def S28(s, c):
    """A17 pad reported down while X moves"""
    ck(c, "homing", s.home())
    s.cmd("M111")
    s.run(0.3)
    s.plant.force = {"X3": True, "X2": False}
    s.run(0.2)
    ck(c, "A17 raised", s.b("M216"))
    ck(c, "X stopped", not s.b("M1336"))
    s.plant.violations = []          # injected sensor fault


def S29(s, c):
    """A18 X path through a forbidden zone"""
    ck(c, "homing", s.home())
    s.set_zone(640, 0, 300, 320)
    xs = []
    s.hook = lambda t: xs.append(t.xpos())
    s.start_auto(0)
    s.pedal()
    s.run(4)
    ck(c, "A18 raised", s.b("M217"))
    ck(c, "X never entered the zone", all(not (300 <= x <= 320) for x in xs))
    ck(c, "D680 shows path blocked", s.w("D680") & (1 << 9))


def S30(s, c):
    """A18 Y path through a forbidden zone"""
    ck(c, "homing", s.home())
    s.set_zone(656, 0, 200, 220)
    ys = []
    s.hook = lambda t: ys.append(t.ypos())
    s.cmd("M113")
    s.run(3)
    ck(c, "A18 raised", s.b("M217"))
    ck(c, "Y never entered the zone", all(not (200 <= y <= 220) for y in ys))


def S31(s, c):
    """Jog stops before a zone (margin 2 mm)"""
    ck(c, "homing", s.home())
    s.set_zone(640, 1, 400, 420)
    s.plc.bits["M104"] = True
    s.run(5)
    s.plc.bits["M104"] = False
    s.run(0.2)
    ck(c, "stopped at 398 mm", abs(s.xpos() - 398) < 0.6)
    s.plc.bits["M104"] = True
    s.run(1)
    s.plc.bits["M104"] = False
    s.run(0.2)
    ck(c, "cannot jog further", abs(s.xpos() - 398) < 0.6)
    ck(c, "no alarm", clean(s))


def S32(s, c):
    """No-drop zone at the print station"""
    ck(c, "homing", s.home())
    s.set_zone(664, 0, 485, 505)
    zs = []
    s.hook = lambda t: zs.append((t.xpos(), t.plant.z))
    s.start_auto(0)
    s.pedal()
    s.run(6)
    ck(c, "A18 raised at the pad-down step", s.b("M217"))
    ck(c, "pad never came down in the zone", all(z < 40 for x, z in zs if 485 <= x <= 505))


def S33(s, c):
    """A19 axis already inside a zone, then jog out"""
    ck(c, "homing", s.home())
    s.set_zone(640, 0, 40, 60)             # around pick = 50 mm
    s.run(0.3)
    ck(c, "A19 raised", s.b("M218"))
    s.reset()
    ck(c, "reset accepted", not s.alarms())
    s.plc.bits["M104"] = True
    s.run(1)
    s.plc.bits["M104"] = False
    s.run(0.3)
    ck(c, "jogged out of the zone", s.xpos() > 60 and not s.alarms())


def S34(s, c):
    """A20 PLC operation error + safe reset"""
    ck(c, "homing", s.home())
    s.plc.put("D1067", 6706)
    s.plc.put("D1068", 1234)
    s.plc.bits["M1067"] = True
    s.run(0.2)
    ck(c, "A20 raised with code/step kept", s.b("M219") and s.w("D683") == 6706 and s.w("D684") == 1234)
    ck(c, "D680 shows PLC error", s.w("D680") & (1 << 12))
    s.cmd("M141")
    s.run(0.5)
    ck(c, "safe reset clears flag and alarm", not s.b("M1067") and not s.alarms())


def S35(s, c):
    """A21 corrupted step register repaired"""
    ck(c, "homing", s.home())
    s.start_auto(2)
    s.run(1.5)
    s.plc.put("D0", 33)
    s.run(0.5)
    ck(c, "A21 raised", s.b("M220"))
    ck(c, "sequence stopped safely, pad up", not s.b("M90") and s.w("D0") == 0)
    ck(c, "no collision", not s.plant.violations)
    s.reset()
    ck(c, "production resumes", s.start_auto(2) and s.prints(1, pedal=False) == 1)


def S36(s, c):
    """Software safe reset during motion"""
    ck(c, "homing", s.home())
    s.start_auto(2)
    s.run(2.2)
    s.cmd("M141")
    s.run(1.5)
    ck(c, "everything stopped, pad up", not s.b("M90") and not s.b("M1336")
       and not s.b("M1337") and s.plant.z < 2)
    ck(c, "no alarm, homing kept", not s.alarms() and s.b("M24"))
    ck(c, "restart works", s.start_auto(2) and s.prints(1, pedal=False) == 1)


def S37(s, c):
    """Restore default parameters"""
    s.plc.put("D502", 4000, True)
    s.set_zone(640, 0, 10, 20)
    s.cmd("M140")
    s.run(0.2)
    ck(c, "print position back to 495.0", s.w("D502", True) == 4950)
    ck(c, "zones cleared", s.w("D642", True) == 0)


def S38(s, c):
    """Black box records the first alarm"""
    ck(c, "homing", s.home())
    n0 = s.w("D682")
    s.start_auto(2)
    s.run(2)
    s.plant.force = {"X16": False}
    s.run(0.5)
    ck(c, "one black-box entry", s.w("D682") == n0 + 1)
    ck(c, "entry code = A13", s.w("D3750") == 13)
    ck(c, "entry keeps the step it happened in", s.w("D3751") in AUTO_STEPS[1:])


def S39(s, c):
    """Diagnostics: why won't it run (D680)"""
    s.plc.bits["M508"] = True
    ck(c, "not homed shown", s.w("D680") & 1)
    ck(c, "login missing shown", s.w("D680") & (1 << 6))
    ck(c, "homing", s.home())
    ck(c, "not-homed bit clears", not s.w("D680") & 1)
    s.plant.force = {"X15": False}
    s.run(1)
    ck(c, "air low shown", s.w("D680") & (1 << 4))


def S40(s, c):
    """Operators, shifts, session log"""
    p = s.plc
    p.put("D3000", 1234)
    p.put("D3001", 5678)
    ck(c, "homing", s.home())
    ck(c, "start refused without login", not s.start_auto(0) and s.b("M137"))
    p.put("D600", 9999); s.cmd("M130"); s.run(0.1)
    ck(c, "unknown code rejected", s.b("M133") and not s.b("M132"))
    p.put("D600", 1234); s.cmd("M130"); s.run(0.1)
    ck(c, "1234 logged in", s.b("M132") and s.w("D601") == 1234)
    s.start_auto(0)
    ck(c, "3 prints", s.prints(3) == 3)
    ck(c, "1234 shift count = 3", s.w("D616") == 3)
    p.put("D600", 5678); s.cmd("M130"); s.run(0.1)
    ck(c, "session record for 1234", s.w("D3100") == 1234 and s.w("D3106") == 3)
    ck(c, "2 more prints on 5678", s.prints(2) == 2 and s.w("D616") == 2)
    s.plant.clock0 += 4 * 3600
    s.run(0.3)
    ck(c, "shift change closes 5678 session", s.w("D3110") == 5678 and s.w("D3116") == 2)
    ck(c, "shift 2, counters cleared", s.w("D602") == 2 and s.w("D616") == 0)
    s.cmd("M101"); s.run(8)
    s.cmd("M131"); s.run(0.2)
    ck(c, "logout", not s.b("M132") and s.w("D601") == 0)
    ck(c, "no alarm, no collision", clean(s))


def S41(s, c):
    """Power cycle keeps parameters, comes up safe"""
    ck(c, "homing", s.home())
    s.plc.put("D502", 5200, True)
    s.start_auto(2)
    s.run(2)
    old = s.plc
    s2 = TSim()
    for k, v in old.words.items():
        n = int(k[1:]) if k[0] == "D" and k[1:].isdigit() else -1
        if 200 <= n <= 999 or 2000 <= n <= 9999:
            s2.plc.words[k] = v
    for k, v in old.bits.items():
        if k[0] == "M" and k[1:].isdigit() and 500 <= int(k[1:]) <= 999:
            s2.plc.bits[k] = v
    s2.plant.z = s.plant.z
    s2.plc.bits["M508"] = False
    s2.run(2)
    ck(c, "not homed, not running", not s2.b("M24") and not s2.b("M90"))
    ck(c, "pad goes up", s2.plant.z < 2)
    ck(c, "parameter kept", s2.w("D502", True) == 5200)
    ck(c, "home + print after power-up", s2.home() and s2.start_auto(2)
       and s2.prints(1, pedal=False) == 1)
    s.plc.cov |= s2.plc.cov


def fuzz(seed, s, c):
    rnd = random.Random(seed)
    cmds = ["M100", "M101", "M102", "M103", "M108", "M109", "M110", "M111", "M112",
            "M113", "M117", "M141"]
    faults = ["X10", "X15", "X16", "X4", "X5", "X6", "X7"]
    s.home()
    for _ in range(160):
        r = rnd.random()
        if r < 0.45:
            s.cmd(rnd.choice(cmds))
        elif r < 0.55:
            s.plc.bits["M120"] = rnd.random() < 0.7
        elif r < 0.65:
            s.plc.put("D554", rnd.randint(0, 2))
        elif r < 0.72:
            s.pedal()
        elif r < 0.80:
            j = rnd.choice(["M104", "M105", "M106", "M107"])
            s.plc.bits[j] = True
            s.run(rnd.uniform(0.05, 0.6))
            s.plc.bits[j] = False
        elif r < 0.90:
            s.plant.force = {rnd.choice(faults): False}
            s.run(rnd.uniform(0.02, 0.5))
            s.plant.force = {}
        else:
            s.plc.put(rnd.choice(["D0", "D1", "D2"]), rnd.randint(-5, 200))
        s.run(rnd.uniform(0.05, 0.8))
    ck(c, "no collision in 160 random actions", not s.plant.violations)
    _clear(s)
    s.run(1)
    s.cmd("M141")
    s.run(1)
    s.reset()
    rec = s.home() and s.start_auto(2) and s.prints(1, pedal=False) == 1
    ck(c, "recovers: safe reset, home, print", rec)


def S42(s, c):
    """Random fuzz #1"""
    fuzz(1, s, c)


def S43(s, c):
    """Random fuzz #2"""
    fuzz(2, s, c)


def S44(s, c):
    """Random fuzz #3"""
    fuzz(3, s, c)
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

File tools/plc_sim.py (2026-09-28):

#!/usr/bin/env python3
"""Minimal Delta DVP-SV2 IL interpreter + pad-printer plant model.

Runs plc/TampoPrinter_SV2.il against a simple physical model of the
machine (X/Y stepper axes, Z pneumatic cylinder, sensors) and checks the
safety invariants every scan.  It covers only the instruction subset the
program uses and simplifies pulse-output behaviour, so it verifies the
LOGIC (sequence, interlocks, alarms), not Delta firmware timing.

Usage:  python3 tools/plc_sim.py            (runs all scenarios)
"""
import math
import re
import sys
from collections import defaultdict

SCAN = 0.005                       # s per scan
IL_PATH = "plc/TampoPrinter_SV2.il"


# ---------------------------------------------------------------- PLC core
def s16(v):
    v &= 0xFFFF
    return v - 0x10000 if v & 0x8000 else v


def s32(v):
    v &= 0xFFFFFFFF
    return v - 0x100000000 if v & 0x80000000 else v


class PLC:
    def __init__(self, path):
        self.prog = []
        self.labels = {}
        self.src = []                      # IL line number per instruction
        for lineno, raw in enumerate(open(path, encoding="utf-8"), 1):
            line = raw.split("//")[0].strip()
            if line:
                p = line.split()
                if re.fullmatch(r"P\d+", p[0]) and len(p) == 1:
                    self.labels[p[0]] = len(self.prog)
                    self.prog.append(("LABEL", []))
                    self.src.append(lineno)
                    continue
                self.prog.append((p[0], p[1:]))
                self.src.append(lineno)
        self.cov = set()                   # outputs executed with power flow
        # precompile compare instructions (speed)
        self.cmp = []
        for op, a in self.prog:
            m = re.match(r"^(D?)(LD|AND|OR)(=|<>|>=|<=|>|<)$", op)
            self.cmp.append((m.group(1) == "D", m.group(2), self.CMP[m.group(3)]) if m else None)
        self._ixc = {}
        self._kc = {}
        self.bits = defaultdict(bool)      # X, Y, M, T(contact)
        self.words = defaultdict(int)      # D, T(value) - 16-bit signed
        self.tacc = defaultdict(float)     # timer accumulators (s)
        self.edge = {}                     # per-instruction previous value
        self.pulse = {}                    # pulse channel state
        self.first = True

    # --- operand access -------------------------------------------------
    def bit(self, name):
        return self.bits[self.ix(name)]

    def setbit(self, name, v):
        self.bits[self.ix(name)] = bool(v)

    def ix(self, op):
        p = self._ixc.get(op)
        if p is None:
            m = re.fullmatch(r"([A-Z])(\d+)([EF]\d)", op)
            p = (m.group(1), int(m.group(2)), m.group(3)) if m else False
            self._ixc[op] = p
        if p:
            return "%s%d" % (p[0], p[1] + s16(self.words[p[2]]))
        return op

    def val(self, op, dbl=False):
        k = self._kc.get(op)
        if k is not None:
            return k
        op = self.ix(op)
        if op.startswith("K"):
            if op.startswith("K4M"):
                base = int(op[3:])
                return sum((1 << i) for i in range(16) if self.bits["M%d" % (base + i)])
            self._kc[op] = int(op[1:])
            return self._kc[op]
        if op.startswith("T"):
            return int(self.tacc[op] / self.tbase(op))
        if op[0] in "EF":
            return s16(self.words[op])
        n = int(op[1:])
        if dbl:
            lo = self.words["D%d" % n] & 0xFFFF
            hi = self.words["D%d" % (n + 1)] & 0xFFFF
            return s32(lo | (hi << 16))
        return s16(self.words[op])

    def put(self, op, v, dbl=False):
        op = self.ix(op)
        if op[0] in "EF":
            self.words[op] = s16(v)
            return
        n = int(op[1:])
        if dbl:
            v &= 0xFFFFFFFF
            self.words["D%d" % n] = s16(v & 0xFFFF)
            self.words["D%d" % (n + 1)] = s16(v >> 16)
        else:
            self.words[op] = s16(v)

    def put64(self, op, v):
        n = int(op[1:])
        v &= (1 << 64) - 1
        for i in range(4):
            self.words["D%d" % (n + i)] = s16((v >> (16 * i)) & 0xFFFF)

    @staticmethod
    def tbase(t):
        n = int(t[1:])
        return 0.01 if 200 <= n <= 239 else 0.1

    # --- scan -------------------------------------------------------------
    CMP = {"=": lambda a, b: a == b, "<>": lambda a, b: a != b, ">": lambda a, b: a > b,
           "<": lambda a, b: a < b, ">=": lambda a, b: a >= b, "<=": lambda a, b: a <= b}
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

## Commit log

2026-09-24 Add control system design for large-format closed-cup pad printer
    - Design review with sizing calculations (Z force, inertia ratio, peak speed,
    regen voltage, pneumatic E-stop behaviour, cycle-time optimisation)
    - Full I/O, M, D and timer allocation for DVP-28SV211T
    - Homing / auto / ink / manual state machines
    - Reference IL program with single DDRVA/DZRN per channel and three-layer
    anti-collision interlocks between X, Y and the pneumatic Z
    - DOP-107BV screen structure, access levels, recipe and tag list
    - Power, EMC/grounding, safety circuit, alarm table and drive fault routine
    - Axis sizing script
    Claude-Session: https://claude.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
    [tag_list.csv]
2026-09-24 Add BOM cost estimate (Shahrivar 1405)
    Claude-Session: https://claude.ai/code/session_017NnjGKvzA2teNKjrkmLnCh
    [bom_estimate.csv]
2026-09-24 Add USD equivalent and international reference prices to BOM
    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
    [bom_estimate.csv]
2026-09-24 Use sourced international USD prices in BOM
    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
    [bom_estimate.csv]
2026-09-24 Fix USD range formatting in BOM
    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
2026-09-27 Update redesign with X stroke/mass, pad size, and Y belt drive data
    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
2026-09-27 Record Y belt pitch and X shaft size; explain motor sizing per axis
    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
2026-09-27 Add final BOM for the redesign based on field data
    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
    [bom_final_v2.csv]
2026-09-28 Update PLC program and docs to redesign v2
    - X: gearbox 1:3 scale (100 p/mm), 620 mm stroke; Y: 24T pulley on
    existing 20 mm belt
    - Z safe-height sensor (X20) and above-safe flag; X moves once the pad
    clears the safe height
    - Early Z descent window (D550, M507) with A10/A17 immediate-stop nets
    - Parallel inking default on, pre-pick mode (M506, D552), pedal latch
    - Docs 02-06, HMI tags, sizing script and README aligned; docs 01/07
    marked as based on the initial data
    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
    [tag_list.csv]
2026-09-28 Add IL simulator with plant model; fix A10/A17 detection
    - tools/plc_sim.py runs the IL against an X/Y/Z plant model and checks
    collision invariants: 4 option scenarios + 2 fault scenarios pass
    - A10/A17 now also check the move request (M50/M52): the permit drop cut
    the pulse contact before the busy flag could raise the alarm, so X
    stopped silently short of target
    - Default early-descent lead reduced to 5 mm
    - Comment-free IL for WPLSoft paste and device comment list
    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
    [device_comments.csv]
2026-09-28 Add print modes (1:1, 1:N multi-hit, continuous) and worker main screen
    - PLC: D554 print mode, D555 N, D556 burst counter; multi-hit requests the
    next print itself; M502 now derived from D554
    - Simulator: multi-hit (6 prints / 2 pedals) and continuous scenarios pass
    - HMI main screen rebuilt for operators: large mode tiles, big N stepper,
    big start/stop, large counters; technical options moved to screen 4
    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
    [tag_list.csv]
2026-09-28 Main screen: big print-position control; refined styling with IRANSans stack
    - PLC clamps pick/print positions to 0..soft max instead of raising A15
    - HMI: print distance in mm with +/-1 and +/-10 buttons and track map,
    refined panel styling, IRANSans first in the font stack
    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
2026-09-28 Add operator login, shifts, session log and ERP gateway
    - PLC N13: 40-operator registry (last 4 digits of national ID), login /
    logout, 3 clock-based shifts, per-operator shift counters, 64-record
    session ring buffer written by subroutine P1, live block D3080-D3095
    - Start requires login (M508); login/logout command bits reset after use
    - Simulator: CALL/SRET/FEND, CJ, FOR/NEXT, index registers, MUL/ADD, RTC;
    operator scenario passes (11 checks) with all earlier scenarios
    - tools/erp_gateway.py: Modbus TCP polling, exactly-once session records
    with seq wrap-around, local journal with retry; unit + E2E tested
    - HMI: operator chip, login keypad, operator shift count on main screen,
    o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
    [erp_gateway.py, plc_sim.py]
2026-09-28 Forbidden zones, error handling, safe reset, black box; full test suite
    PLC:
    - Forbidden zones on HMI: 4 X, 2 Y, 2 no-drop (on X); jog clamps before
    the edge (P2/P3/P6/P7), path check before every move (P4/P5, A18),
    inside-zone immediate stop (A19), no-drop check in Z permit and pad-down
    steps (P8)
    - A20 PLC operation error with code/step, A21 step-register sanity repair,
    software safe reset (M141), restore defaults (M140 via P9), black box of
    16 alarms (P11), D680 'why won't it run' reasons
    - Start refused while a batch is complete
    Tests:
    - tools/test_suite.py: 52 scenarios, 262 checks, run in parallel; every
    alarm A01-A21 by fault injection, zones, recovery, power cycle, rando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
    [plc_sim.py, test_suite.py]
2026-09-28 BOM: add Ethernet module DVPEN01-SL and network parts to final purchase list
    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
    [bom_final_v2.csv]
2026-09-28 Add parametric 3D design of the whole machine (frame + parts)
    CadQuery model cad/tampo_machine.py generates the assembly STEP, per-part
    STEP files, 1:1 DXF flat patterns for all plates, a hidden-line general
    arrangement DXF, tube cut list, full parts list, an automatic check report
    (interference in 7 motion states, key clearances, frame deflection under
    print force, moving mass and X motor re-check) and an offline 3D viewer
    with print-cycle animation. Docs 13 explains AutoCAD use, build steps,
    assumptions to verify and the light-curtain safety-distance issue.
    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
    [M01.step, M02.step, M10.step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]
2026-09-28 3D viewer: inline three.js so it loads without CDN access
    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
    [M01.step, M02.step, M10.step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]
2026-09-28 3D model: cup axis at 90° to X (cliché along Y), X belt moved inside between rails
    The ink station is rebuilt with the cliché long side and the cup travel along Y,
    matching the existing machine. The base frame widens to 950 mm on the ink side,
    the cabinet moves to the right side. The X belt now runs between the rails,
    105 mm from the carriage centre instead of 215 mm; the check report gains an
    off-centre drive calculation. All interference checks pass.
    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
    [M01.step, M02.step, M10.step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]
2026-09-28 Redesign for disc printing: pad reaches 700 mm out onto a bolted disc table
    The part is a 2 mm plastic disc (e.g. OD 1000 / ID 500) lying on a table
    outside the machine. The body is shortened to 600 mm around the ink station,
    the X beams (now RHS 120x60x5) cantilever 920 mm past front posts placed
    directly under them so the pad exits through a window, and X travel becomes
    1010 mm. A disc table with a lazy-susan turntable, a centring ring and a 120°
    index pin is bolted to the body so the print force closes inside the steel;
    the report shows the body would tip if the table were free. PLC defaults
    (pick 50, print 495, soft max 1010), tests, HMI mockup, BOM rail/belt lengths
    and docs are update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
    [M01.step, M02.step, M10.step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]
2026-09-28 Z sensing: inductive M12 sensors on a steel flag instead of cylinder reed sensors
    Three PR12-4DN sensors on a slotted bracket under the carriage read one
    3x20x40 steel flag on the Z head plate. X20 becomes a zone sensor (ON from
    fully up down to safe height), so the PLC now sets M26 = X20 directly: a
    broken wire or a lost flag reads 'not safe' and X cannot move. A09 also
    trips on 'UP without SAFE'. Simulator, 2 new scenarios (54/54 pass), 3D
    model (switch points checked from geometry), BOM and docs updated.
    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
    [M01.step, M02.step, M10.step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]
2026-09-28 Jam protection for X and cup axes: stop, back off on reset, current-limit tuning
    A closed-loop driver ALM while its axis runs a DDRVA move is now recorded as
    a jam with its direction (M180-M183). The pulses stop at once and the driver
    goes limp; the reset that clears A02/A03 then moves the jammed axis back
    D690 / D692 (default 5 mm, clamped 0-20 mm) at creep speed, once, and the
    axis stays unhomed. Three new scenarios (X both directions, cup) pass; 57/57.
    Docs 06 gain the commissioning procedure that turns the stepper's current
    setting into a force limit (find the lowest reliable current, set 1.4x),
    plus measuring friction with a push-pull gauge. HMI setup rows, tag list
    and device comments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
    [device_comments.csv, tag_list.csv]
2026-09-28 3D model: detailed purchased parts, fasteners, gussets, foot plates, flanged ties
    New cad/parts_lib.py builds catalogue-like geometry: HGR rails with
    counterbores and screws, HGH blocks with seals and grease nipple, NEMA24
    motors, PLF60 gearbox, SC63 tie-rod cylinder, toothed HTD pulleys, closed
    belt loops, link-by-link drag chain, 4V320 valve, LMF bushings, levelling
    feet, E-stops, tower light. Plates get corner radii (also in DXF) and polygon
    outlines; portals get gussets, legs get foot plates, the disc-table ties get
    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
    [M01.step, M02.step, M10.step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]
2026-09-30 X travel 750 mm with a 1060 mm HGR20 rail (HIWIN standard length)
    The X travel is now the model parameter (750 mm, pad 440 mm beyond the
    body). The rail length is computed as the shortest HIWIN standard length
    ((n-1)x60 + 2x20) that covers travel + block envelope + 40 mm margin at
    each end: 1060 mm. Beams, belt, idler, limit switches and the report follow;
    tip deflection drops to 0.09 mm. The report gains a rail section (length,
    end margins, static safety factor 70 per block under full print force).
    PLC soft max D506 = 750.0 mm; tests, HMI mockup, tag list, BOM (rail row,
    totals) and docs updated. 57/57 PLC scenarios, no 3D interference.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
    [M01.step, M02.step, M10.step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]
